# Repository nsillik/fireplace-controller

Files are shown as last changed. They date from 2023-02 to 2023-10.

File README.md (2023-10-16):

# Nick's Fireplace Controller Thingy

## Why did you make this?

In 2022 we bought an _old_ house. A big ol' victorian built in 1891 which had been converted to a triplex. Unfortunately during this conversion they ripped out all 8 or so original fireplaces an bricked them up. Lame. So, we though we'd put in some gas fireplaces. We did! Then we needed a way to control them, so we bought this amazing remote control system for $500 each:

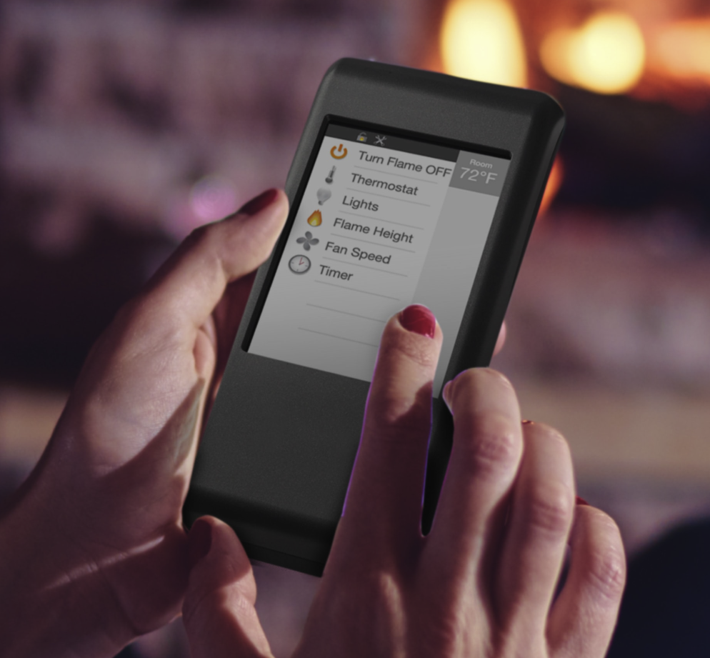
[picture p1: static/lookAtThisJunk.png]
Look at this garbage, just embarrasing


Yes, that's a resistive touch screen. Yes, it really is that ugly and clunky. Yes it did somehow cost $500 dollars. No, that is not my hand. It also does all sorts of annoying things, like only allow you to adust the time by one minute, so if you want to run your fireplace for 2 hours, have fun hitting the (again, resistive) "add minute" button _one hundred and twenty times_.

I hated this, my wife ([@jensillik](https://github.com/jensillik)) hated it, so we decided to do something about it. And here it is.

## How did you make it?

Well, like every computer person of a certain age, I have a giant pile of electronics, raspberry pis, arduinos, ESP8266s, ESP32s, PICs, PIDs, and whatnot lying around that I always pretended I would do something useful with. Mostly I would make an LED blink every few seconds, or say "I'm going to build a robot" and then… make an LED blink every few seconds.

So I gathered up some of my bits and bobs – namely an ESP32, a breadboard, some resistors, a relay, and _of course_ some LEDs for blinking – and slapped them together into some configuration that I was pretty sure would actually control the fireplace's electronics. Then I wrote some firmware code in ESP-IDF that actually turns on and off the relay (_and_ blinks LEDs). I wrote an iOS app (that was ugly), then Jen made some beautiful Figma designs, and so I made the app pretty! Finally I (tried) to build the schematics and PCB layouts for eventual actual-production of hardware!

That all became the following three things:

- *Flicker*: the firmware running on an ESP32 which handles wifi networking, a custom UDP protocol for remote control, and hareware control of the relay for turning the fireplace on and off.

- *Flame*: an iOS app, written in SwiftUI, for the users (all two of us) to control the fireplaces and view their statuses.

- *Spark*: a [KiCad](https://www.kicad.org/) project with schematics, BOM, and PCB layout for eventually actually manufacturing a good looking piece of hardware instead of a breadboard shoved under the fireplace.

Read on for details of all three

### ⚡️ Flicker - ESP32 Firmware

If you're in to electronics projects and somehow haven't heard of the [ESP32](https://www.espressif.com/en/products/socs/esp32), you're missing out. What a cool little chip! It's got:

- A dual core processor!
- 520KB of RAM!
- 448KB of ROM!
- WiFi (802.11 b/g/n)!
- Bluetooth (including BLE)!
- Tons of GPIO, ADCs, DACs, SPI, I2S, I2C, and more!

And it costs something like $6 for a devevelopment board!

For this project it's probably a bit of overkill, of course, since I'm using exactly _one_ GPIO. But the WiFi is _way_ easier – and cheaper – to get up and running than screwing around with an Arduino and some sort of shield. Also I had like 10 of them in a drawer, so why not?

When programming the ESP32 you can either use the Arduino SDK that everyone knows and loves, or Expressif's [ESP-IDF](https://docs.espressif.com/projects/esp-idf/en/latest/esp32/get-started/). I've done a bunch of things (like… making LEDs blink _a lot_) in Arduino, so I decided to use ESP-IDF just for fun.

For development I used [VSCode](https://code.visualstudio.com/) and the [PlatformIO](https://platformio.org/) extension which has boards and extensions and libraries and whatnot for the ESP32.

There's really only three interesting pieces of the code:

- The communcation protocol handler
- The wifi code
- The main app that ties it all together

I won't talk much about the last two, as they're pretty much just copies of the reference implementations for each from Expressif's docs with some things hardcoded for my network, like my WPA2 key (please don't hack me).

The communications handler (in [`/flicker/src/listener.c`](/flicker/src/listener.c)) is fun, and has a good description of the custom protocol in it. Here's how it works:

`udp_server_task` is a function that you pass to [FreeRTOS's](https://www.freertos.org/index.html) [`xTaskCreate`](https://www.freertos.org/a00125.html). This creates a task which FreeRTOS will schedule (somehow! I've not dug too deep into the guts).

This `udp_server_task` then binds a UDP (`SOCK_DGRAM`) listener on port `42069` (sorry, sorry, I'm trying to delete it), and then just busyloops listening for any messages. "Messages" here are just a super-simple protocol:

```
// 
// Command structure:
// Clients send commands in the following format:
// 0000 0000 0000 0000
// ^^|---------------|
// ||        | 
// ||        \--------> For command `10` The amount of time, in seconds to turn on for (for turn on command). Otherwise unused (zero is recommended)
// ||  
// \\-----------------> The command to send `00` for turn off, `01` for status, `10` for turn on
// 
// Server always replies with its status, either:
//  - `0000 0000 0000 0000` for off
//  - `10XX XXXX XXXX XXXX` for on, with the Xs being the time remaining in seconds
```

Basically a client can do three things:
- Send `0x4000`, requesting the status
- Send `0x8000 | (0x3FFF & 0xXXXX)` to turn the fireplace on for `XXXX` seconds (well, with the top two bits masked off)
- Send `0x0000` to turn the fireplace off.

When the server recieves these from the clients it updates it's current status which is just a shared (kinda gross, I know) `uint16_t`, and then sends the current (or updated) status back to the client.

There's another FreeRTOS task in `listener.c` called `statusLoop` which, every second, takes a look at the current status, and makes sure that the hardware is doing the right thing. That is:

- If the current status is `on`, decrement the time remaining by one second, and if it's now zero set the status to `off`.
- If the current status if `on`, and there's time remaining, make sure the `RELAY_PIN` is set to on. This closes the relay and the fireplace turns – or stays – on fire.
- If the current status is `off`, open the relay thereby turning the fireplace off, extinguishing the flame.

That's about it!

You'll see how this is all hooked up in [`flicker/src/main.c`](/flicker/src/main.c), which only does three things:

1. Sets up the networking (lines 12-21)
2. Schedules the two tasks above (lines 22 and 23).

That's it! Now we're ready for a client to actually start talking to it.

### 🔥 Flame - iOS App

And this is that client. An iOS app, written in SwiftUI, designed by the wonderul Jen Sillik. Here's the design:

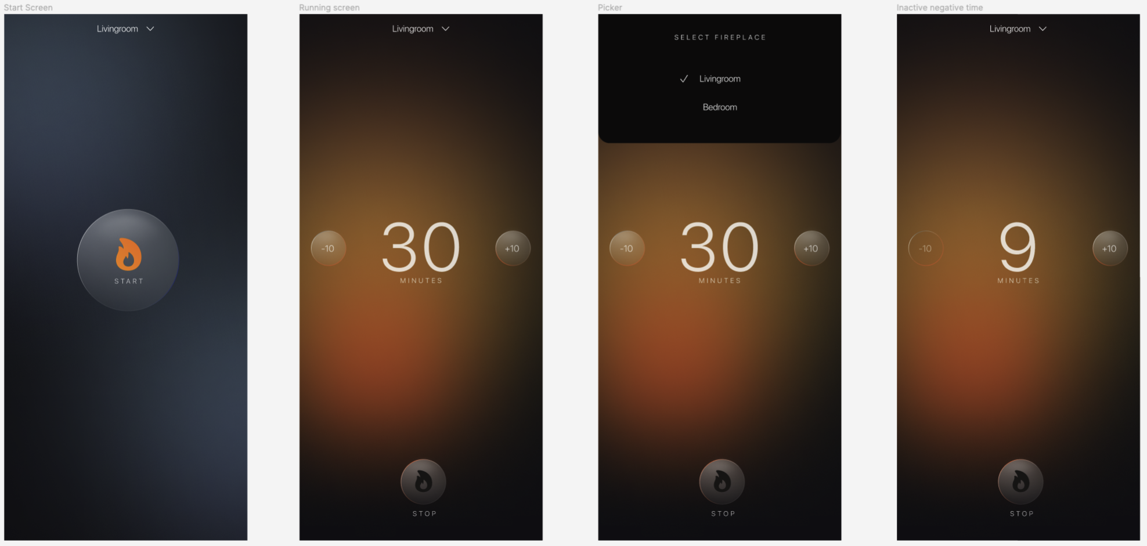
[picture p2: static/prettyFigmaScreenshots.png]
A screenshot of Figma showing designs for the iOS app


There's only a few big pieces here:

- A `FireplaceService` which handles communication with the `Flicker` controller, as well as a test version for using in Xcode Previews.
- A `MainScreen` which is 100% of the UI and logic.
- A couple views like the custom `Picker`, the `GlassButtonStyle`, and the pretty `BackgroundView`.

#### `FireplaceService`

The [`FireplaceService`](/flame/flame/Services/FireplaceService.swift) is really the heart of the application. It's a reasonably simple protocol to conform to:

```swift
protocol FireplaceService: ObservableObject {
  var fireplaces: [Fireplace] { get }
  func turnOnFireplace(_ fireplace: Fireplace, minutes: UInt16) async -> Fireplace
  func turnOffFireplace(_ fireplace: Fireplace) async -> Fireplace
}
```

You can get a list of fireplaces. You can turn on the fireplace. You can turn off the fireplace. Not really much else to do! The `LiveFireplaceService` implements the real-for-real version of this which connects to the fireplaces in my house. The IP addresses are hardcoded, since I have my DHCP server always assign the same IP to the devices (because I'm lazy and didn't feel like doing mDNS in ESP-IDF, maybe some day).

Basically when this guy is `init`-ed it connects to all of the hardcoded fireplaces, gets their status, and then sets a timer to check on the status of the fireplaces every 20 seconds (I had it doing it every 200ms, but that was silly!). This is all done using the built in [`NWConnection`](https://developer.apple.com/documentation/network/nwconnection) which is pretty straightforward.

The connecting happens in the `connectTo` function which is pretty boring boilerplate, so I'm not going to say anymore about that.

The `requestStatus(fireplace:, connection:)` method sends the status message (`0x4000`), and that's it. Messages recieved _from_ the `Flicker` controllers are handled by the `receive(fireplace:, connection:)` method, and literally just update our internal list of fireplaces.

The `turnOnFireplace(_ fireplace: Fireplace, minutes: UInt16)` and `turnOffFireplace(_ fireplace:)` methods just send the corresponding commands to the specified `Fireplace`. Easy-peasy.

Alllll of this is then injected into the SwiftUI Environment as an `EnvironmentObject` as a lazy-man's form of dependency injection.

#### `MainScreen`

The [`MainScreen`](/flame/flame/MainScreen.swift) is the only screen in the app (if only every app was just a single screen…), it's got a `FireplaceService` that it gets like so:
```swift
@EnvironmentObject var fireplaceService
```

And it keeps its state updated based on the currently selected fireplace (and that fireplaces current state). And then (depending on the current state), it has buttons to turn on, turn off, and adjust the time of the current selected fireplace.

#### Some rando views

There's a couple views in here too, but they're not to interesting. Quickly:

- [`Picker`](/flame/flame/Views/Picker.swift): is just a custom little picker view to match Jen's designs. You give it `options`, and it has a `@Binding` for the currently selected option. Neato!
- [`GlassButton`](/flame/flame/Views/GlassButton.swift): is a custom `ButtonStyle` for making the glassy looking buttons. There's actually a little bug here, but I haven't got a chance to sit down w/ my fantastic designer to work them out. It's good enough for now!
- [`BackgroundView`](/flame/flame/Views/BackgroundView.swift): is the pretty view that's the background of the whole app. It's a steely blue-gray color when the fireplace is off, and a warm orange-yellow color when the fireplace is on. Eventually I'm going to make this pretty and feel more alive.

#### That's it

Yeah, really. That's the whole app

### ✨ Spark - Hardware Design

As an added challenge I am trying to actually get the hardware manufactured. I haven't done it yet, and it'll probably be a disaster, but you can take a look at my attempts!

I'm using [KiCad](https://www.kicad.org/), a free and open-source EDA tool. To start, I needed to build a schematic. I used the [ESP32-DevKitC V4](https://docs.espressif.com/projects/esp-idf/en/latest/esp32/hw-reference/esp32/get-started-devkitc.html) as my starting guide. This includes:

- The ESP32
- A usb connector
- A [`CP2102N`](https://www.silabs.com/documents/public/data-sheets/cp2102n-datasheet.pdf) USB-to-UART controller for serial access
- An [`AS1117`](http://www.advanced-monolithic.com/pdf/ds1117.pdf) voltage regulator for going from USBs 5v to the 3.3v that the ESP32 runs on.
- A few buttons, transistors, caps, resistors, diodes, and – of course – blinking LEDs.

On top of that I added a [SRD-03VDC-SL-C](https://pdf1.alldatasheet.com/datasheet-pdf/view/1132027/SONGLERELAY/SRD-03VDC-SL-C.html) relay for actually controlling the fireplace. Oh yeah, and there's some transistors and resistors and diodes around the relay so that it… relays correctly? IDK 🤷‍♀️

I laid that all out in the schematic editor – mostly according to datasheets, example circuits, and with the help of a few buddies – and it ended up looking like this:

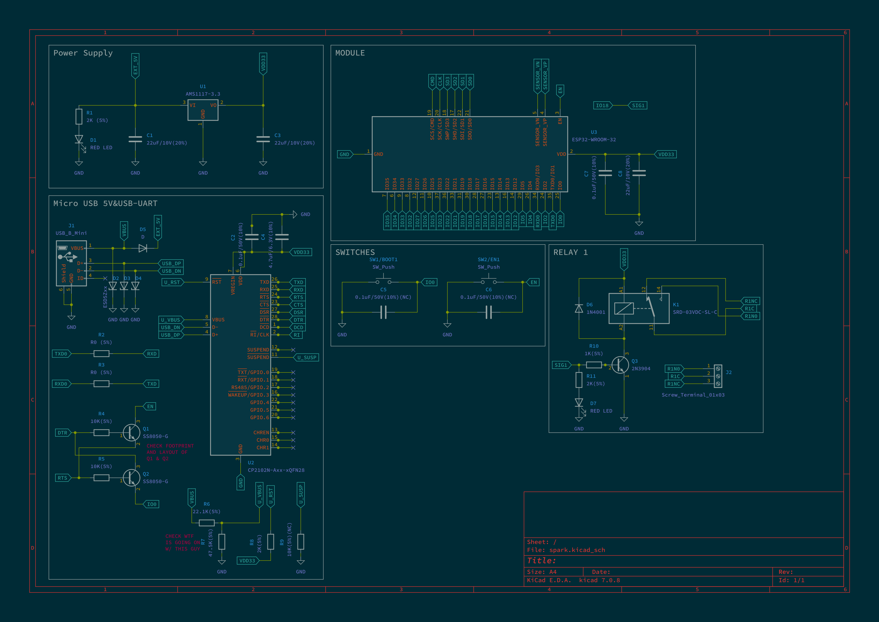
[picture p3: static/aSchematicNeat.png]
A schematic, there's a lot going on here


After that I had to put together the BOM and footprints (although, I'm pretty sure I got some wrong, will be doing like 10 more reviews before ordering):

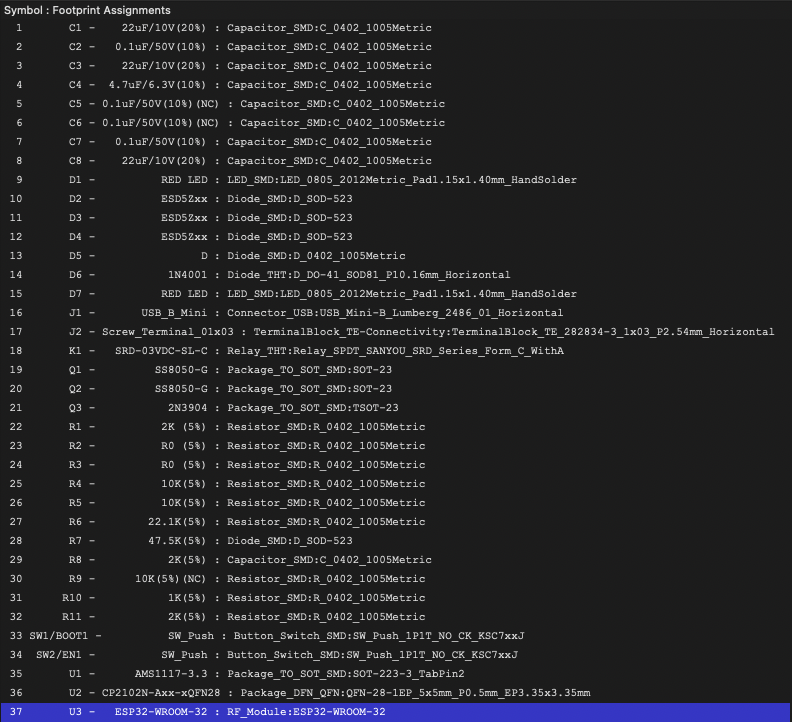
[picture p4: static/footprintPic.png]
Footprint pic


And then, for the hard part, laying out a PCB. Okay, I'm terrible at this, and this was like my 12th attempt. I got everything hooked up, but it's still _really ugly_. It looks like this:

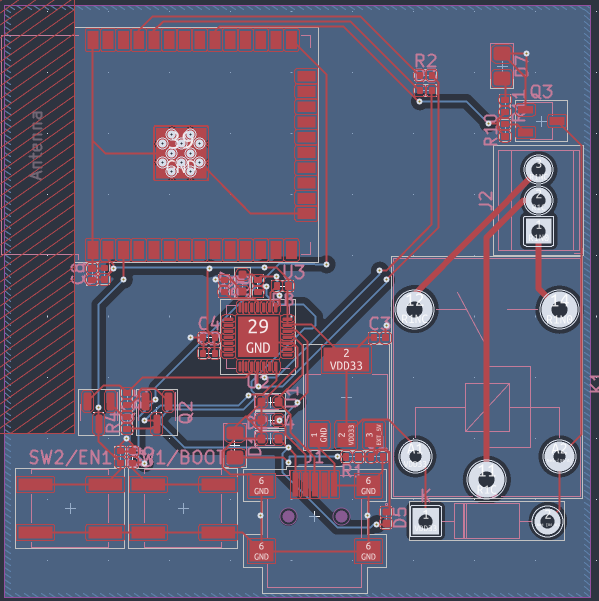
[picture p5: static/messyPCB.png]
Just the sloppiest PCB layout you've ever seen. I'm sorry


And, one day, when I send it to [JLCPCB](https://jlcpcb.com/) for assembly, it'll end up looking something like this:

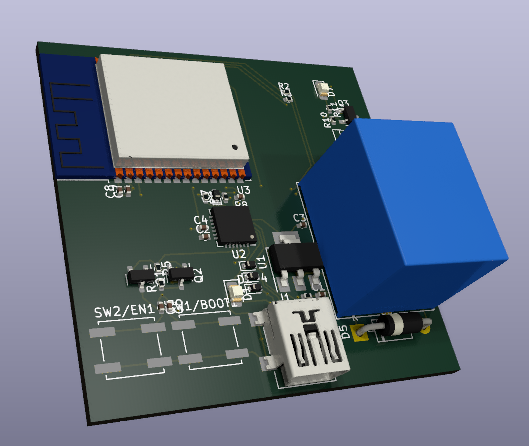
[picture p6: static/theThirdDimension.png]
A 3d rending of the PCB… uhhh… I think that diode looks to big, hm, probably going to have to fix that


### ✍️ What's left to do?

Does it work? Yes! Am I done? Probably not. There's a few more things I'd like to do, most of which I mentioned above:

- Prettier animations in the app! Especially making the background feel a bit more alive.
- Fixing the `GlassButtonStyle` to not be kinda-wrong at times
- Reviewing and checking the schematics (and trying to force friends to do the same) to spot any bugs.
- Probably re-laying out the PCB another 15 or so times until I'm happy with it. It's a bit bigger than I'd like it to be. Maybe I can find a smaller relay?

### 🧨 Is this safe?

God, I hope so 😬

### That's it

If you read this far, sorry! Hope you learned something, even if that something was "don't hire @nsillik for electrical engineering!".

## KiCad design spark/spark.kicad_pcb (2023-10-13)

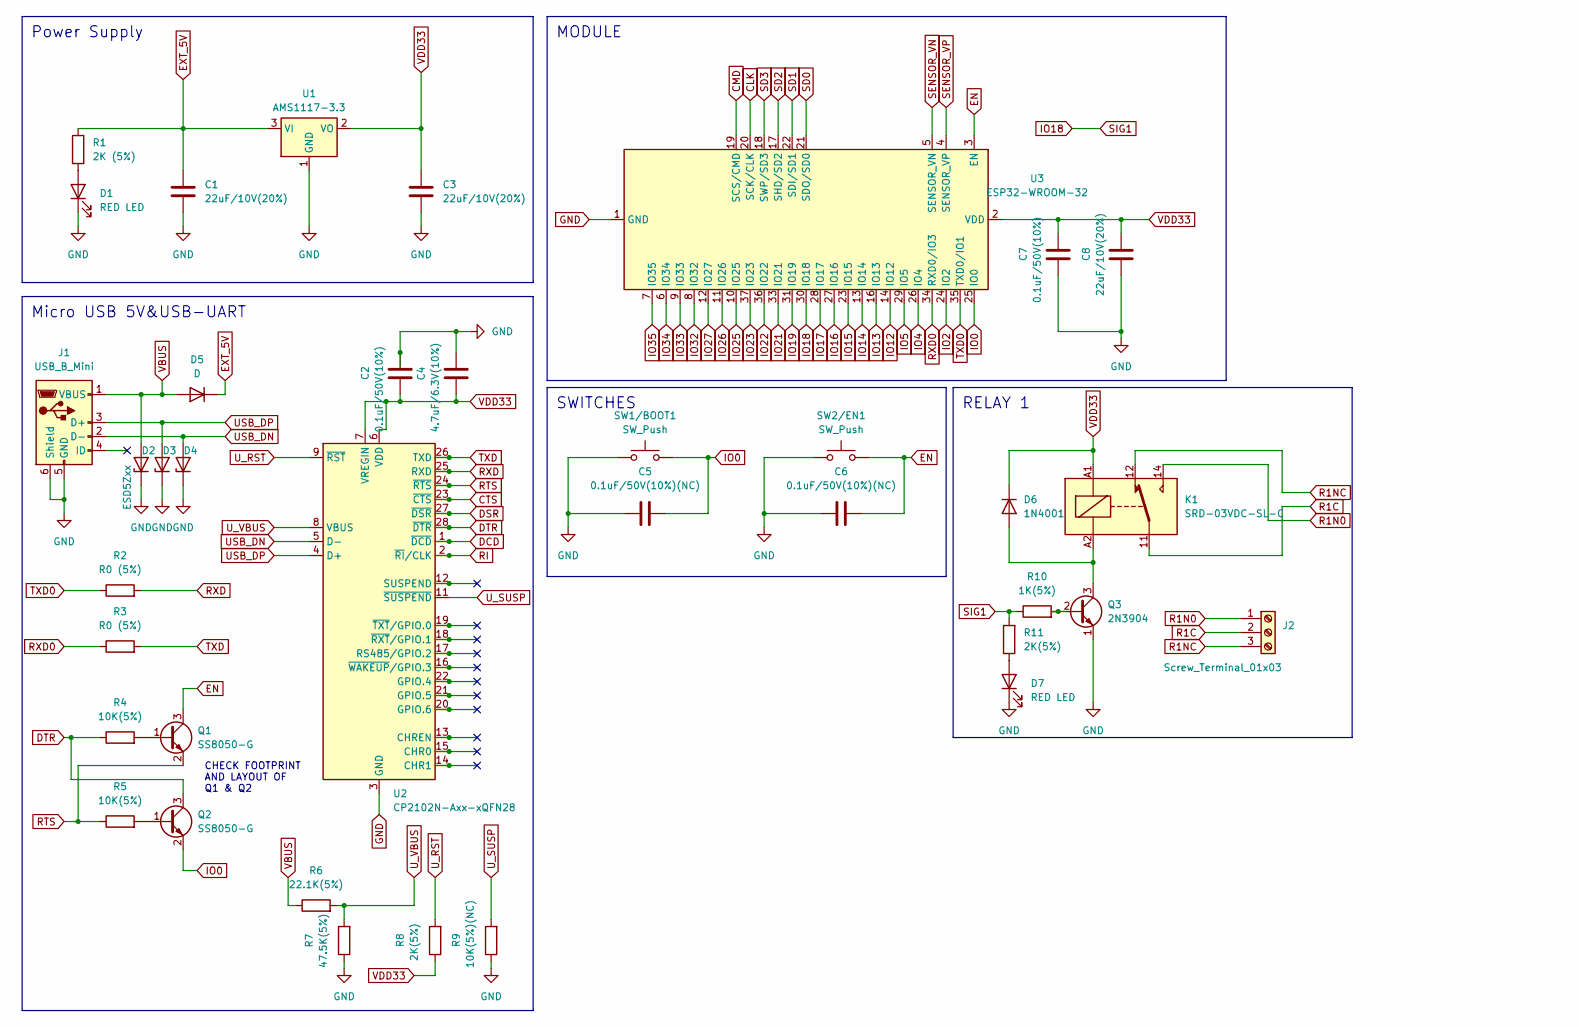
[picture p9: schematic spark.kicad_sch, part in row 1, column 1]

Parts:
C1, C3, C8: 22uF/10V(20%); C_0402_1005Metric
C2, C7: 0.1uF/50V(10%); C_0402_1005Metric
C4: 4.7uF/6.3V(10%); C_0402_1005Metric
C5, C6: 0.1uF/50V(10%)(NC); C_0402_1005Metric
D1, D7: RED LED; LED_0805_2012Metric_Pad1.15x1.40mm_HandSolder
D2, D3, D4: ESD5Zxx; D_SOD-523
D5: D; D_0402_1005Metric
D6: 1N4001; D_DO-41_SOD81_P10.16mm_Horizontal
J1: USB_B_Mini; USB_Mini-B_Lumberg_2486_01_Horizontal
J2: Screw_Terminal_01x03; TerminalBlock_TE_282834-3_1x03_P2.54mm_Horizontal
K1: SRD-03VDC-SL-C; Relay_SPDT_SANYOU_SRD_Series_Form_C_WithA
Q1, Q2: SS8050-G; SOT-23
Q3: 2N3904; TSOT-23
R1: 2K (5%); R_0402_1005Metric
R2, R3: R0 (5%); R_0402_1005Metric
R4, R5: 10K(5%); R_0402_1005Metric
R6: 22.1K(5%); R_0402_1005Metric
R7: 47.5K(5%); D_SOD-523
R8: 2K(5%); C_0402_1005Metric
R9: 10K(5%)(NC); R_0402_1005Metric
R10: 1K(5%); R_0402_1005Metric
R11: 2K(5%); R_0402_1005Metric
SW1/BOOT1, SW2/EN1: SW_Push; SW_Push_1P1T_NO_CK_KSC7xxJ
U1: AMS1117-3.3; SOT-223-3_TabPin2
U2: CP2102N-Axx-xQFN28; QFN-28-1EP_5x5mm_P0.5mm_EP3.35x3.35mm
U3: ESP32-WROOM-32

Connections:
CLK: U3.20 (SCK/CLK)
CMD: U3.19 (SCS/CMD)
CTS: U2.23 (~CTS)
DCD: U2.1 (~DCD)
DSR: U2.27 (~DSR)
DTR: Q2.3 (C), R4.1, U2.28 (~DTR)
EN: C6.2, Q1.3 (C), SW2/EN1.2, U3.3 (EN)
EXT_5V: C1.1, D5.1 (K), R1.1, U1.3 (VI)
GND: C1.2, C2.1, C3.2, C4.1, C5.1, C6.1, C7.2, C8.2, D1.1 (K), D2.1 (K), D3.1 (K), D4.1 (K), D7.1 (K), J1.5 (GND), J1.6 (Shield), Q3.1 (E), R7.1, R9.1, SW1/BOOT1.1, SW2/EN1.1, U1.1 (GND), U2.3 (GND), U2.29 (GND), U3.1 (GND), U3.15 (GND), U3.38 (GND), U3.39 (GND); also elsewhere on the board
IO0: C5.2, Q2.2 (E), SW1/BOOT1.2, U3.25 (IO0)
IO2: U3.24 (IO2)
IO4: U3.26 (IO4)
IO5: U3.29 (IO5)
IO12: U3.14 (IO12)
IO13: U3.16 (IO13)
IO14: U3.13 (IO14)
IO15: U3.23 (IO15)
IO16: U3.27 (IO16)
IO17: U3.28 (IO17)
IO18: R10.1, R11.2, U3.30 (IO18)
IO19: U3.31 (IO19)
IO21: U3.33 (IO21)
IO22: U3.36 (IO22)
IO23: U3.37 (IO23)
IO25: U3.10 (IO25)
IO26: U3.11 (IO26)
IO27: U3.12 (IO27)
IO32: U3.8 (IO32)
IO33: U3.9 (IO33)
IO34: U3.6 (IO34)
IO35: U3.7 (IO35)
unnamed: D1.2 (A), R1.2
unnamed: D6.2 (A), K1.A2, Q3.3 (C)
unnamed: D7.2 (A), R11.1
unnamed: Q1.1 (B), R4.2
unnamed: Q2.1 (B), R5.2
unnamed: Q3.2 (B), R10.2
R1C: J2.2, K1.11
R1N0: J2.1, K1.14
R1NC: J2.3, K1.12
RI: U2.2 (~RI/CLK)
RTS: Q1.2 (E), R5.1, U2.24 (~RTS)
RXD: R2.2, U2.25 (RXD)
RXD0: R3.1, U3.34 (RXD0/IO3)
SD0: U3.21 (SDO/SD0)
SD1: U3.22 (SDI/SD1)
SD2: U3.17 (SHD/SD2)
SD3: U3.18 (SWP/SD3)
SENSOR_VN: U3.5 (SENSOR_VN)
SENSOR_VP: U3.4 (SENSOR_VP)
TXD: R3.2, U2.26 (TXD)
TXD0: R2.1, U3.35 (TXD0/IO1)
USB_DN: D4.2 (A), J1.2 (D-), U2.5 (D-)
USB_DP: D3.2 (A), J1.3 (D+), U2.4 (D+)
U_RST: R8.2, U2.9 (~RST)
U_SUSP: R9.2, U2.11 (~SUSPEND)
U_VBUS: R6.2, R7.2, U2.8 (VBUS)
VBUS: D2.2 (A), D5.2 (A), J1.1 (VBUS), R6.1; also elsewhere on the board
VDD33: C2.2, C3.1, C4.2, C7.1, C8.1, D6.1 (K), K1.A1, R8.1, U1.2 (VO), U2.6 (VDD), U2.7 (VREGIN), U3.2 (VDD)

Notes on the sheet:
RELAY 1
SWITCHES
Power Supply
Micro USB 5V&USB-UART
MODULE
CHECK FOOTPRINT AND LAYOUT OF Q1 & Q2

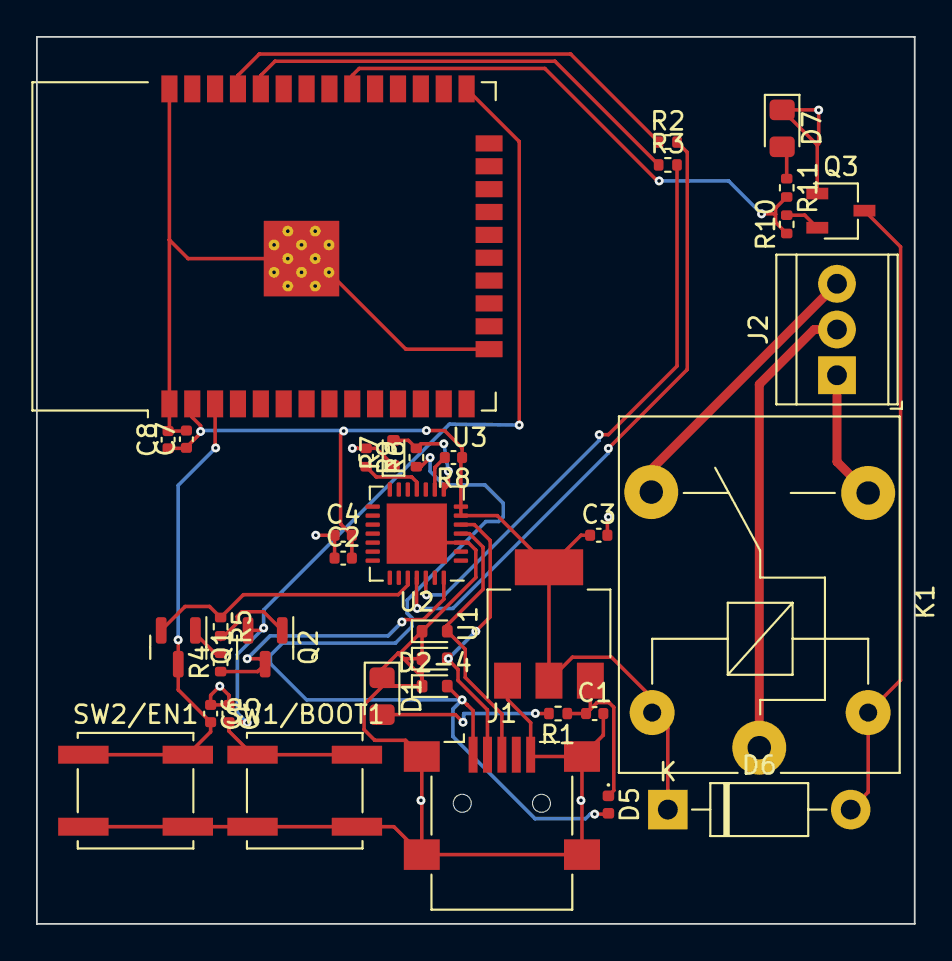
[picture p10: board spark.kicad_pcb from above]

Board: 2 copper layers, 48.8 x 49.3 mm, 37 parts (0 on the bottom side), 27 nets.

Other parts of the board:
D2-4: ESD5Zxx; D_SOD-523

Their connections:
GND: D2-4.1 (K); also elsewhere on the board
VBUS: D2-4.2 (A); also elsewhere on the board

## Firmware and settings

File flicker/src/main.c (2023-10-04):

#include <driver/gpio.h>
#include <freertos/FreeRTOS.h>
#include <freertos/task.h>
#include "nvs_flash.h"
#include "esp_log.h"
#include "esp_err.h"
#include "wifi.h"
#include "listener.h"

void app_main() {
    //Initialize NVS
    esp_err_t ret = nvs_flash_init();
    if (ret == ESP_ERR_NVS_NO_FREE_PAGES || ret == ESP_ERR_NVS_NEW_VERSION_FOUND) {
      ESP_ERROR_CHECK(nvs_flash_erase());
      ret = nvs_flash_init();
    }
    ESP_ERROR_CHECK(ret);
    ESP_ERROR_CHECK(esp_netif_init());

    ESP_LOGI("FLICKER", "ESP_WIFI_MODE_STA");
    wifi_init_sta();
    xTaskCreate(&udp_server_task, "udp_server", 4096, (void*)AF_INET, 5, NULL);
    xTaskCreate(&statusLoop,"STATUS_LOOP",4096,NULL,5,NULL);
}

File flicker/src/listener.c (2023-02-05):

#include <string.h>
#include <sys/param.h>
#include <driver/gpio.h>
#include <lwip/netdb.h>

#include "freertos/FreeRTOS.h"
#include "freertos/task.h"
#include "esp_system.h"
#include "esp_wifi.h"
#include "esp_event.h"
#include "esp_log.h"
#include "nvs_flash.h"
#include "esp_netif.h"
#include "listener.h"

#include "lwip/err.h"
#include "lwip/sockets.h"
#include "lwip/sys.h"

uint16_t processCommand(uint16_t command);

#define PORT 42069 
#define LED_PIN 21
static const char *TAG = "example";

// 
// Command structure:
// Clients send commands in the following format:
// 0000 0000 0000 0000
// ^^|---------------|
// ||        | 
// ||        \--------> For command `10` The amount of time, in seconds to turn on for (for turn on command). Otherwise unused (zero is recommended)
// ||  
// \\-----------------> The command to send `00` for turn off, `01` for status, `10` for turn on
// 
// Server always replies with its status, either:
//  - `0000 0000 0000 0000` for off
//  - `10XX XXXX XXXX XXXX` for on, with the Xs being the time remaining in seconds

uint16_t currentStatus = 0x00000000;

uint16_t getCurrentStatus() {
    return currentStatus;
}

void udp_server_task(void *pvParameters)
{
    char rx_buffer[128];
    char addr_str[128];
    int addr_family = (int)pvParameters;
    int ip_protocol = 0;
    struct sockaddr_in6 dest_addr;

    while (1) {

        if (addr_family == AF_INET) {
            struct sockaddr_in *dest_addr_ip4 = (struct sockaddr_in *)&dest_addr;
            dest_addr_ip4->sin_addr.s_addr = htonl(INADDR_ANY);
            dest_addr_ip4->sin_family = AF_INET;
            dest_addr_ip4->sin_port = htons(PORT);
            ip_protocol = IPPROTO_IP;
        } else if (addr_family == AF_INET6) {
            bzero(&dest_addr.sin6_addr.un, sizeof(dest_addr.sin6_addr.un));
            dest_addr.sin6_family = AF_INET6;
            dest_addr.sin6_port = htons(PORT);
            ip_protocol = IPPROTO_IPV6;
        }

        int sock = socket(addr_family, SOCK_DGRAM, ip_protocol);
        if (sock < 0) {
            ESP_LOGE(TAG, "Unable to create socket: errno %d", errno);
            break;
        }
        ESP_LOGI(TAG, "Socket created");

        int enable = 1;
        lwip_setsockopt(sock, IPPROTO_IP, IP_PKTINFO, &enable, sizeof(enable));

        // Set timeout
        struct timeval timeout;
        timeout.tv_sec = 10;
        timeout.tv_usec = 0;
        setsockopt (sock, SOL_SOCKET, SO_RCVTIMEO, &timeout, sizeof timeout);

        int err = bind(sock, (struct sockaddr *)&dest_addr, sizeof(dest_addr));
        if (err < 0) {
            ESP_LOGE(TAG, "Socket unable to bind: errno %d", errno);
        }
        ESP_LOGI(TAG, "Socket bound, port %d", PORT);

        struct sockaddr_storage source_addr; // Large enough for both IPv4 or IPv6
        socklen_t socklen = sizeof(source_addr);

        struct iovec iov;
        struct msghdr msg;
        struct cmsghdr *cmsgtmp;
        u8_t cmsg_buf[CMSG_SPACE(sizeof(struct in_pktinfo))];

        iov.iov_base = rx_buffer;
        iov.iov_len = sizeof(rx_buffer);
        msg.msg_control = cmsg_buf;
        msg.msg_controllen = sizeof(cmsg_buf);
        msg.msg_flags = 0;
        msg.msg_iov = &iov;
        msg.msg_iovlen = 1;
        msg.msg_name = (struct sockaddr *)&source_addr;
        msg.msg_namelen = socklen;

        gpio_pad_select_gpio(LED_PIN);
        gpio_set_direction (LED_PIN,GPIO_MODE_OUTPUT);
        while (1) {
            ESP_LOGI(TAG, "Waiting for data");
            gpio_set_level(LED_PIN,1);
            int len = recvmsg(sock, &msg, 0);
            gpio_set_level(LED_PIN,0);
            // Error occurred during receiving
            if (len < 0) {
                if (errno != 11) {
                  ESP_LOGE(TAG, "recvfrom failed: errno %d", errno);
                }
                break;
            } else {
                // Data received
                // Get the sender's ip address as string
                if (source_addr.ss_family == PF_INET) {
                    inet_ntoa_r(((struct sockaddr_in *)&source_addr)->sin_addr, addr_str, sizeof(addr_str) - 1);
                    for ( cmsgtmp = CMSG_FIRSTHDR(&msg); cmsgtmp != NULL; cmsgtmp = CMSG_NXTHDR(&msg, cmsgtmp) ) {
                        if ( cmsgtmp->cmsg_level == IPPROTO_IP && cmsgtmp->cmsg_type == IP_PKTINFO ) {
                            struct in_pktinfo *pktinfo;
                            pktinfo = (struct in_pktinfo*)CMSG_DATA(cmsgtmp);
                            ESP_LOGI(TAG, "dest ip: %s\n", inet_ntoa(pktinfo->ipi_addr));
                        }
                    }
                } else if (source_addr.ss_family == PF_INET6) {
                    inet6_ntoa_r(((struct sockaddr_in6 *)&source_addr)->sin6_addr, addr_str, sizeof(addr_str) - 1);
                }

                rx_buffer[len] = 0; // Null-terminate whatever we received and treat like a string...
                ESP_LOGI(TAG, "Received %d bytes from %s:", len, addr_str);
                ESP_LOGI(TAG, "%s", rx_buffer);
                if (len == 2) {
                    uint16_t command = (rx_buffer[1] << 8) | (rx_buffer[0]);
                    ESP_LOGI(TAG, "Got command 0x%04X", command);
                    processCommand(command);
                }
                ESP_LOGI(TAG, "Current status is 0x%04X", currentStatus);
                int err = sendto(sock, &currentStatus, 2, 0, (struct sockaddr *)&source_addr, sizeof(source_addr));
                if (err < 0) {
                    ESP_LOGE(TAG, "Error occurred during sending: errno %d", errno);
                    break;
                }
            }
        }

        if (sock != -1) {
            ESP_LOGE(TAG, "Shutting down socket and restarting...");
            shutdown(sock, 0);
            close(sock);
        }
    }
    vTaskDelete(NULL);
}

uint16_t processCommand(uint16_t command) {
    if (command & 0x8000) {
        // Turn on
        ESP_LOGI(TAG, "TURN ON FOR %d SECONDS", command & 0x3FFF);
        currentStatus = command;
    } else if (command & 0x4000) {
        // status
        return currentStatus;
    } else if (!(command & 0x3000)) {
        currentStatus = 0x0000;
        return currentStatus;
    }
    return currentStatus;
}

#define RELAY_PIN 18

void statusLoop(void *pvParams) {
    gpio_pad_select_gpio(RELAY_PIN);
    gpio_set_direction (RELAY_PIN,GPIO_MODE_OUTPUT);
    while (1) {
        if (currentStatus & 0x8000) {
            // we're currently on, decrement the time
            int16_t timeRemaining = currentStatus & 0x3FFF;
            timeRemaining -= 1;
            if (timeRemaining == 0) {
                currentStatus = 0x0000;
            } else {
                currentStatus = 0x8000 | (timeRemaining);
            }
            if (currentStatus & 0x8000) {
                gpio_set_level(RELAY_PIN,1);
            }
        } else {
            gpio_set_level(RELAY_PIN,0);
        }
        vTaskDelay(1000/portTICK_RATE_MS);
    }
}

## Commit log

2023-01-08 wifi working, esp32 setup done
2023-02-05 get rid of useless led blink
2023-10-04 add initial, empty, KiCAD project
    [spark.kicad_pcb, spark.kicad_sch]
2023-10-08 Add basic esp32 board (and some bonus design fixes to app)
    [spark.kicad_pcb, spark.kicad_sch]
2023-10-08 whoops, forgot the switches
    [spark.kicad_sch]
2023-10-11 Working PCB #1
    [spark.kicad_pcb, spark.kicad_sch]
2023-10-11 fix all design rules issues
    [spark.kicad_pcb]
2023-10-13 Another checkpoint, going to do layout again for funsies
    [spark.kicad_pcb]
2026-03-15 Fix thread safety, retain cycles, and cleanup in FireplaceService
    - Add @MainActor to protocol and implementations for thread safety
    - Fix retain cycles with [weak self] in Timer, stateUpdateHandler, and receiveMessage closures
    - Add exponential backoff for reconnection (capped at 30s)
    - Fix cancelled handler removing redundant connection.cancel() call
    - Fix Int16/UInt16 mismatch using Command.getStatus.commandValue
    - Remove unused fireplace parameter from requestStatus
    - Remove ObservableObject requirement from protocol (uses @Observable)
    - Change turnOn/turnOffFireplace to return Void instead of Fireplace
    - Replace print statements with os.Logger
    - Extract magic numbers to constants (port,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
